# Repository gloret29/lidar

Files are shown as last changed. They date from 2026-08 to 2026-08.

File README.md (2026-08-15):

# Scanner 3D LiDAR DIY

Scanner d'intérieur sur trépied photo, à base d'un LiDAR 2D **STL-19P**
(FHL-LD19P, famille LD19) dont le plan de balayage vertical est mis en rotation
autour d'un axe vertical. L'ESP32-S3
acquiert les mesures et les diffuse en Wi-Fi ; la station hôte reconstruit le
nuage de points 3D.

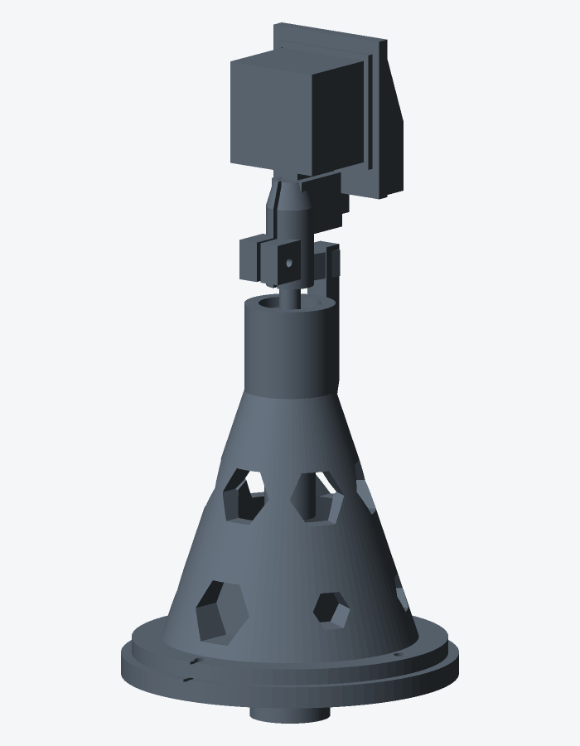
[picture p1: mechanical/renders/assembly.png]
Vue d'assemblage


**Environ 205 € de matériel**, pour un nuage de 225 000 à 900 000 points par
scan (selon durée), à ±5 cm, en 45 à 180 secondes.

## Documentation

### Comprendre

| Document | Contenu |
|---|---|
| [PROJECT.md](PROJECT.md) | Spécification et périmètre du projet |
| [docs/geometry.md](docs/geometry.md) | **Fondement mathématique** : pourquoi cette architecture, transformation exacte, budget d'erreur |
| [docs/architecture.md](docs/architecture.md) | Tâches du firmware, protocole UDP, pipeline hôte |

### Construire

| Document | Contenu |
|---|---|
| [docs/build.md](docs/build.md) | **Guide pas à pas** : de la commande au premier scan |
| [docs/bom.md](docs/bom.md) | Nomenclature complète, y compris les pièces manquantes |
| [docs/printing.md](docs/printing.md) | Réglages d'impression, calibration des ajustements |
| [docs/mechanical.md](docs/mechanical.md) | Conception cotée, justification des choix |
| [docs/assembly.md](docs/assembly.md) | Montage mécanique détaillé |
| [docs/wiring.md](docs/wiring.md) | Brochage, alimentation, plans SVG, réglage TMC2209 |
| [docs/wifi.md](docs/wifi.md) | Configuration réseau par portail captif |
| [docs/web.md](docs/web.md) | Panneau web : commande, matériel, diagnostics, réglages |
| [docs/ota.md](docs/ota.md) | Mise à jour du firmware par le réseau |

### Utiliser

| Document | Contenu |
|---|---|
| [docs/calibration.md](docs/calibration.md) | Les cinq mesures à effectuer une fois |
| [docs/operation.md](docs/operation.md) | Préparation des lieux, conduite d'un scan, dépannage |
| [docs/open3d.md](docs/open3d.md) | Visualisation, `.pcd`, recalage et maillage avec Open3D |

## Principe

Le STL-19P est un LiDAR **2D** (protocole LD19) : il balaie 360° dans un plan,
à **5 000 mesures/s**, avec détection du verre. Monté **sur la tranche**, ce
plan devient vertical ; en le faisant pivoter de 180° autour de l'axe vertical,
on couvre la sphère complète exactement une fois.

Conséquence contre-intuitive mais essentielle : **l'angle interne du LiDAR est
l'élévation, et l'angle moteur est l'azimut**.

$$
X = \rho \cos\psi \cos\theta, \quad
Y = \rho \sin\psi \cos\theta, \quad
Z = \rho \sin\theta
$$

Le détail, et le contre-exemple qui disqualifie la formulation inverse, sont
dans [docs/geometry.md](docs/geometry.md).

## Structure du dépôt

```
lidar/
├── firmware/            ESP32-S3 (PlatformIO / Arduino / FreeRTOS)
│   ├── boards/          DevKitC-1 N16R8 (16 Mo + PSRAM)
│   ├── data/            image LittleFS
│   ├── include/         config, protocole, pilotes
│   └── src/             amorce OTA, tâches, parseur LD19, axe de lacet
├── host/                Station hôte Python
│   ├── src/lidar_host/  protocole, transformation, visualisation, simulateur
│   ├── tests/           tests protocole / géométrie / simulateur (sans matériel)
│   └── calibration.json paramètres de calibration
├── mechanical/
│   ├── openscad/        sources paramétriques
│   ├── stl/             pièces prêtes à imprimer
│   ├── renders/         aperçus
│   └── tools/           génération et rendu
└── docs/                documentation détaillée
```

## Démarrage rapide

Le parcours complet (commande → impression → montage → firmware → premier
scan) est dans **[docs/build.md](docs/build.md)**.

### 1. Pièces mécaniques

```bash
cd mechanical/openscad
make                       # STL dans ../stl/
```

Imprimer **`test_fits` en premier** pour calibrer les ajustements, reporter les
valeurs dans `params.scad`, puis relancer `make`. Détails dans
[docs/printing.md](docs/printing.md).

### 2. Firmware

```bash
cd firmware
pio run -e seed -t upload     # amorce OTA, une fois en USB
pio device monitor
```

Au premier démarrage, se connecter au point d'accès `LiDAR-Scanner-Setup` pour
configurer le Wi-Fi, l'adresse de la station hôte et le mot de passe OTA.
Puis téléverser le firmware scanner : `pio run -e ota -t upload` (voir
[docs/build.md](docs/build.md) § 6.2).

Le scanner **reste au repos** après connexion. Ouvrir
`http://lidar-scanner.local/` pour lancer un balayage, vérifier l'état du
**matériel** connecté (LiDAR, entraînement, IMU), ajuster les réglages et
redémarrer si besoin. Voir [docs/web.md](docs/web.md).

Les mises à jour passent par le réseau, sans rebrancher l'USB — soit depuis
PlatformIO, soit en déposant le `.bin` sur la même page :

```bash
pio run -e ota -t upload      # firmware scanner
pio run -e ota -t uploadfs    # filesystem LittleFS
# si lidar-scanner.local ne résout pas :
pio run -e ota -t upload --upload-port 192.168.x.x
```

Voir [docs/ota.md](docs/ota.md).

### 3. Station hôte

```bash
cd host
python -m venv .venv && source .venv/bin/activate
pip install -e .
```

Sans matériel, valider la chaîne avec le simulateur UDP (deux terminaux) :

```bash
# A — sous WSL : export DISPLAY=:0 si la fenêtre Open3D échoue
lidar-visualize --port 9000

# B
lidar-simulate --host 127.0.0.1 --port 9000 --fast
```

Sans fenêtre graphique : `lidar-receive --port 9000 --output scans/sim.pcd --auto-stop`.

Avec le scanner : lancer d'abord `lidar-visualize` / `lidar-receive`, puis le
balayage depuis `http://lidar-scanner.local/`.

Guide Open3D : [docs/open3d.md](docs/open3d.md).

### 4. Post-traitement

```bash
lidar-receive --port 9000 --output scans/salon_pos1.pcd --auto-stop
lidar-register scans/salon_*.pcd --output salon.pcd
lidar-mesh salon.pcd --output salon.ply
```

## Ce que fait — et ne fait pas — ce scanner

| Usage | Adapté |
|---|---|
| Plan d'étage, surfaces, volumes | Oui |
| Modèle d'ambiance pour de la 3D | Oui |
| Vérifier l'encombrement d'un meuble | Oui |
| BIM de détail, détection de collisions | Non |
| Relevé patrimonial, contrôle au millimètre | Non |

Précision réaliste : **±5 cm**, espacement des points de 3 à 7 cm à 5 m. Un
scanner terrestre professionnel atteint ±2 mm et des dizaines de millions de
points, pour 15 000 à 50 000 €.

## Matériel

ESP32-S3 DevKitC-1 (N16R8) · LiDAR STL-19P (FHL-LD19P) · NEMA 17 pas à pas
(17HS4401 ou équivalent 4 fils) · TMC2209 · MPU6050 · 2 × roulements 608ZZ ·
power bank USB-C PD + trigger 12 V + buck 5 V · châssis imprimé en 3D avec
insert laiton 1/4"-20 × 10 × 8 mm.

Nomenclature détaillée, y compris les compléments à acquérir, dans
[docs/bom.md](docs/bom.md).

## Licence

MIT

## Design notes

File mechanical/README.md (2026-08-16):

# Mécanique

Pièces du châssis, entièrement paramétriques (OpenSCAD).

Assemblage

## Contenu

```
mechanical/
├── openscad/     sources paramétriques
│   ├── params.scad       TOUTES les cotes, point d'entrée unique
│   ├── lib.scad          primitives réutilisables
│   ├── test_fits.scad    coupon de calibration
│   ├── test_lidar_fit.scad  coupon empreinte STL-19P
│   ├── base_plate.scad   01 — plateau de base
│   ├── bearing_tower.scad 02 — colonne à roulements
│   ├── lidar_cradle.scad 03 — berceau LiDAR
│   ├── electronics_box.scad / _lid.scad  04/05 — boîtier
│   ├── assembly.scad     vue d'ensemble
│   └── Makefile
├── stl/          pièces prêtes à imprimer
├── renders/      aperçus
└── tools/
    ├── render_all.sh     génération STL + PNG
    └── stl_preview.py    rasteriseur STL en Python pur
```

## Génération

```bash
cd openscad
make                # STL dans ../stl/
make renders        # PNG (nécessite un contexte OpenGL)
```

Sans serveur graphique — machine distante, conteneur, CI — utiliser le
rasteriseur en Python pur, qui n'a aucune dépendance :

```bash
OPENSCAD=/chemin/vers/openscad ./tools/render_all.sh
```

```bash
# Aperçu d'une pièce isolée, sous l'angle de son choix
python3 tools/stl_preview.py stl/bearing_tower.stl /tmp/apercu.png \
    --azim 40 --elev 20 --color 5aa469
```

## Paramétrage

Toutes les cotes sont dans
[`openscad/params.scad`](openscad/params.scad). Modifier une valeur et relancer
`make` la propage à l'ensemble des pièces.

Les deux paramètres à ajuster impérativement avant d'imprimer :

| Paramètre | Comment l'obtenir |
|---|---|
| `fit_press`, `fit_slide` | Imprimer `test_fits`, voir [docs/printing.md](../docs/printing.md) |
| `lidar_optical_offset` | Mesurer au pied à coulisse, voir [docs/calibration.md](../docs/calibration.md) § 1 |

## Pièces

| Pièce | Rôle | Impression |
|---|---|---|
| `test_fits` | **À imprimer en premier** : calibration des ajustements | 15 min |
| `test_lidar_fit` | Empreinte STL-19P (trous + nappe) sans le berceau | ~20 min, à plat |
| `base_plate` | Interface trépied, support moteur, embase colonne | Retournée |
| `bearing_tower` | Porte les deux 608ZZ, **définit l'axe** | 5 périmètres, 40 % |
| `lidar_cradle` | Présente le STL-19P (3 oreilles M2,5) sur la tranche | Couchée |
| `electronics_box` + `_lid` | Boîtier sanglé sur le trépied | Standard |

Voir [docs/mechanical.md](../docs/mechanical.md) pour les cotes et la
justification des choix, [docs/printing.md](../docs/printing.md) pour les
réglages, [docs/assembly.md](../docs/assembly.md) pour le montage.

## Vérification

Les six pièces sont rendues sans erreur par OpenSCAD et produisent des solides
manifold. Les contraintes de non-collision (tige contre corps du STL-19P, voile
contre LiDAR, cavité contre moteur, têtes de vis contre cône) sont listées avec
leurs marges dans [docs/mechanical.md](../docs/mechanical.md) § 5.

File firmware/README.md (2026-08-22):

# Firmware ESP32-S3

Firmware PlatformIO du scanner 3D LiDAR.

## Prérequis

- [PlatformIO](https://platformio.org/) (CLI ou extension VS Code / Cursor).
  Sans `pio` dans le PATH : `firmware/.pio-venv/bin/pio`.
- ESP32-S3 DevKitC-1 **N16R8** (16 Mo Flash / 8 Mo PSRAM octale)

## Compilation

Premier flash, **obligatoirement en USB** : l'amorce OTA. Elle ne pilote
ni le LiDAR ni le moteur. Elle ouvre le portail Wi-Fi, puis accepte les
mises à jour du firmware **et** du filesystem LittleFS. Ensuite, plus
besoin de câble.

```bash
pio run -e seed -t upload
pio device monitor
```

Au premier démarrage, se connecter à `LiDAR-Scanner-Setup` pour le Wi-Fi
et le mot de passe OTA. Puis ouvrir `http://lidar-scanner.local/`.

Les mises à jour suivantes, sans USB :

```bash
pio run -e ota -t upload      # firmware scanner
pio run -e ota -t uploadfs    # image LittleFS (data/)
# si mDNS échoue :
pio run -e ota -t upload --upload-port 192.168.x.x
```

Pour itérer sur l'amorce elle-même : `pio run -e seed-ota -t upload`.
Le firmware scanner se compile encore avec `-e usb` si un câble est
branché.

Les dépendances (`WiFiManager`, `TMCStepper`) sont téléchargées automatiquement.
Web + OTA n'en ajoutent aucune : `ArduinoOTA`, `WebServer`, `Update`,
`LittleFS` et `Preferences` font partie du core ESP32.

## Configuration

### Wi-Fi et panneau web — aucun identifiant en dur

Au premier démarrage, l'ESP32 ouvre le point d'accès `LiDAR-Scanner-Setup`. On
y renseigne le réseau local, l'adresse de la station hôte et le mot de passe
du panneau (OTA inclus). Ces valeurs sont persistées en NVS.

Après connexion, ouvrir `http://lidar-scanner.local/` : commande de balayage,
section **Matériel** (Wi‑Fi, LiDAR, entraînement, IMU), diagnostics,
réglages StallGuard / courants / vitesse, redémarrage et OTA.

Voir [docs/wifi.md](../docs/wifi.md), [docs/web.md](../docs/web.md) et
[docs/ota.md](../docs/ota.md).

### Paramètres

- Défauts et brochage : [`include/config.h`](include/config.h)
- Valeurs runtime (persistées) : panneau web → NVS namespace `scanset`

> **Attention** : sur la variante N16R8, les GPIO 33 à 37 sont occupés par la
> PSRAM octale. Les utiliser fait planter la carte au démarrage.

## Organisation

```
firmware/
├── platformio.ini
├── boards/              ESP32-S3 DevKitC-1 N16R8 (16 Mo + PSRAM)
├── data/                image LittleFS (`pio run -t uploadfs`)
├── include/
│   ├── config.h        brochage et défauts
│   ├── protocol.h      datagrammes UDP (v2)
│   ├── ld19.h          analyseur de trames LiDAR
│   ├── mpu6050.h       nivellement IMU, détection de choc
│   ├── scanner.h       axe de lacet
│   ├── settings.h      réglages NVS
│   ├── control.h       file de commandes
│   ├── status.h        télémétrie
│   ├── ota.h           panneau web + OTA
│   └── wifi_setup.h
└── src/
    ├── seed/main.cpp   amorce OTA (premier flash USB)
    ├── main.cpp
    ├── ld19.cpp
    ├── mpu6050.cpp
    ├── scanner.cpp
    ├── settings.cpp
    ├── control.cpp
    ├── status.cpp
    ├── ota.cpp         page unique + ArduinoOTA (firmware + LittleFS)
    └── wifi_setup.cpp
```

## Séquence d'exécution

```
setup()
  ├── réglages NVS
  ├── UART LiDAR + PWM
  ├── TMC2209
  ├── MPU6050 (I2C)
  ├── WiFiManager
  ├── panneau web + ArduinoOTA
  └── tâches

motion_task    attend start/stop/rehome/estop (file FreeRTOS)
lidar_task     UART -> décodage -> file
network_task   file -> datagrammes UDP
web_task       HTTP + ArduinoOTA.handle()
```

Le scanner **ne lance plus de balayage tout seul** au démarrage.

## Points d'implémentation notables

**Les points partent en polaire brut.** La conversion cartésienne est faite
côté hôte. Voir [docs/architecture.md](../docs/architecture.md).

**Débordement de file : on abandonne le point.** Perdre un point est sans
conséquence ; bloquer l'UART corromprait toute une salve.

**StealthChop2 n'est pas un confort.** Les vibrations SpreadCycle se
transmettent au capteur optique.

**L'OTA coupe le moteur avant d'écrire**, et est refusé pendant un balayage.
Comme le scanner démarre au repos, un firmware défectueux reste rattrapable
sans fenêtre artificielle de 10 s. Détails dans [docs/ota.md](../docs/ota.md).

**Les réglages exposés sont bornés dans le firmware** (courants, StallGuard,
vitesse). La calibration géométrique reste sur l'hôte.

## État

Firmware **0.4.5** — homing StallGuard par UART (`SG_RESULT`), sans broche DIAG.

| Fonction | Code | Validation matérielle |
|---|---|---|
| Amorce OTA (`seed`) | OK | OTA firmware + LittleFS |
| Scanner + panneau web | OK | Wi‑Fi, reboot, section Matériel |
| Parseur STL-19P / LD19 | OK | CRC % sur panneau |
| MPU6050 nivellement + choc | OK | `imu_ok` sur panneau |
| TMC2209 + homing StallGuard | OK | Ligne Entraînement → OK après rehome |
| Balayage complet | OK | Premier `.pcd` réel |

À vérifier au montage final :

- [ ] LiDAR : CRC ≥ 95 %, Hz mesuré ≈ consigne (5 Hz)
- [ ] Entraînement : pastille **OK** après **Rehomer** réussi
- [ ] MPU6050 : pastille **OK**, vecteur **g** affiché
- [ ] Scan 180° → `.pcd` cohérent dans Open3D

Le premier téléversement se fait obligatoirement **par USB**, avec
l'environnement `seed`. Les suivants passent par le réseau
(`-e ota -t upload` / `uploadfs`) ou la page web.

La géométrie et le protocole sont couverts par les tests de `host/tests/`.

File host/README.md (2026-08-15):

# Station hôte

Réception UDP, conversion cartésienne, visualisation temps réel et
post-traitement du nuage de points.

## Installation

```bash
python -m venv .venv
source .venv/bin/activate
pip install -e .
# sous WSL2 + WSLg, si lidar-visualize échoue :
export DISPLAY=:0
```

Python ≥ 3.10. Dépendances : NumPy et Open3D. Les commandes `lidar-*` sont
installées par `pip install -e .` (pas besoin de `PYTHONPATH`).

## Utilisation

### Visualisation pendant le scan

```bash
lidar-visualize --port 9000
```

Sous WSL sans affichage : `--headless --output scans/out.pcd`, ou
`lidar-receive` (voir [docs/open3d.md](../docs/open3d.md)).

### Flux de test sans matériel

Dans un terminal :

```bash
lidar-visualize --port 9000
```

Dans un autre :

```bash
lidar-simulate --host 127.0.0.1 --port 9000 --fast
```

Le simulateur envoie une scène synthétique (protocole UDP v2) — par défaut
un **appartement en L avec mobilier** (`--scene apartment`) — **et enregistre**
le nuage dans `scans/simulate.pcd`. Un exemplaire est versionné dans le dépôt,
ainsi que le maillage `scans/simulate.ply`.

```bash
python -c "import open3d as o3d; o3d.visualization.draw_geometries([o3d.io.read_point_cloud('scans/simulate.pcd')])"
python -c "import open3d as o3d; m=o3d.io.read_triangle_mesh('scans/simulate.ply'); m.compute_vertex_normals(); o3d.visualization.draw_geometries([m])"
```

```bash
# Fichier seul, sans UDP
lidar-simulate --fast --no-udp --output scans/sim.pcd

# Pavé vide (ancien comportement)
lidar-simulate --fast --scene box --no-udp

# UDP sans fichier
lidar-simulate --fast --no-save
```

Options : `--scene`, `--width`, `--depth`, `--height`, `--speed`, `--psi-end`,
`--loops 0`, `--calibration`. Détails dans
[docs/open3d.md](../docs/open3d.md#flux-de-test-sans-matériel).

### Enregistrement

```bash
lidar-receive --port 9000 --output scans/salon_pos1.pcd --auto-stop
```

`--auto-stop` arrête la capture à réception du drapeau de fin de balayage.

### Recalage et maillage

```bash
lidar-register scans/salon_*.pcd --output salon.pcd
lidar-mesh salon.pcd --output salon.ply --depth 8 --smooth taubin
# ou relisser un .ply existant :
lidar-mesh scans/simulate.ply --output scans/simulate_smooth.ply --smooth-iter 20
```

## Calibration

[`calibration.json`](calibration.json) regroupe le bras de levier, les
décalages angulaires et le vecteur gravité de référence (`g_zero`, relevable
depuis la section **Matériel** du panneau web). Ces valeurs sont appliquées
**au post-traitement** : les corriger et rejouer un scan ne demande ni
reflashage ni nouvelle acquisition.

Procédures détaillées dans [docs/calibration.md](../docs/calibration.md).

Guide Open3D (fenêtre live, fichiers, ICP, Poisson, dépannage) :
[docs/open3d.md](../docs/open3d.md).

## Tests

```bash
pytest -q
```

38 tests, sans matériel. Ils couvrent le décodage du protocole, la
transformation géométrique (garde-fou contre la formule sphérique naïve) et
le simulateur UDP (dont l'enregistrement du nuage).

## Organisation

```
host/
├── src/lidar_host/
│   ├── protocol.py     décodage UDP v2, vectorisé NumPy
│   ├── transform.py    polaire -> cartésien, calibration, nivellement
│   ├── receiver.py     socket, accumulation, export
│   ├── visualize.py    affichage temps réel Open3D
│   ├── simulate.py     flux UDP de test (pièce synthétique)
│   └── postprocess.py  filtrage, ICP, Poisson
├── tests/
└── calibration.json
```

## Protocole

Spécifié dans
[docs/architecture.md](../docs/architecture.md#protocole-udp-version-2). Les
points arrivent en **polaire brut** : distance et angle d'élévation par point,
azimut en en-tête de datagramme.

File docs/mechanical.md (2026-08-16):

# Conception mécanique

Toutes les cotes sont en millimètres. Le repère d'assemblage a son origine
$z = 0$ sur la **face supérieure du plateau de base**, l'axe $Z$ confondu avec
l'axe de rotation (lacet).

Vue d'assemblage

## 1. Chaîne cinématique

```
                    STL-19P (couché, plan de balayage vertical)
                       │  centre optique : z = 205, sur l'axe
                  ┌────┴────┐
                  │ berceau │  C3 — serre sur la tige
                  └────┬────┘
                       │  tige acier Ø8, z 65 → 180
                  ┌────┴────┐
                  │ 608ZZ   │  z 122 (palier de butée : reprend le poids)
                  │ colonne │  C2
                  │ 608ZZ   │  z 82  (palier de guidage)
                  └────┬────┘
                       │  accouplement flexible 5→8, z 52 → 77
                  ┌────┴────┐
                  │ NEMA 17 │  z 0 → 40
                  └────┬────┘
                  ┌────┴────┐
                  │ plateau │  C1
                  └────┬────┘
                       │  insert 1/4"-20
                    trépied
```

Hauteur totale au-dessus de la semelle du trépied : **229 mm**.
Masse de la tête tournante : environ 110 g (STL-19P ~47 g + berceau 45 g + tige).

## 2. Décisions de conception

### Entraînement direct plutôt que courroie

Le TMC2209 en 1/16 de pas donne $360 / (200 \times 16) = 0{,}1125°$ par
micro-pas, soit 3,5 fois plus fin que le pas de balayage visé (0,4°). Une
réduction par courroie n'apporterait donc aucune résolution utile, tout en
introduisant du jeu et une pièce d'usure supplémentaire. L'entraînement direct
supprime totalement le jeu de renversement.

### Moteur au-dessus du plateau, coaxial

L'axe de rotation et la vis de trépied doivent tous deux passer par le centre.
Le conflit se résout en plaçant le moteur **sur** le plateau (arbre vers le
haut) et l'insert 1/4"-20 **sous** le plateau, dans un bossage. La colonne
coiffe alors le moteur.

### Accouplement flexible, pas rigide

Deux roulements sur une tige rigide plus un accouplement rigide vers le moteur
forment un système hyperstatique : le moindre défaut d'alignement précontraint
les roulements et crée un point dur. Un accouplement à mâchoires absorbe ce
défaut.

### Palier de butée en haut

Le roulement supérieur (z 122) reprend la charge axiale : le moyeu du berceau
prend appui sur sa bague intérieure. Le chemin d'effort est donc
LiDAR → berceau → bague intérieure → billes → bague extérieure → épaulement de
la colonne → plateau → trépied. Le roulement inférieur (z 82) ne travaille
qu'en radial.

## 3. Occultation au nadir

Tout ce qui se trouve sous le LiDAR et sur l'axe se trouve **dans** le plan de
balayage et masque une portion de la sphère autour du nadir.

| Élément | Ø | Distance sous le centre optique | Demi-angle masqué |
|---|---|---|---|
| Sommet du moyeu | 12 | 25 | 13,5° |
| Voile du berceau | 14 (en Y) | 25 | 15,6° |
| Sommet de la colonne | 34 | 72 | 13,3° |
| Contrefort de butée | 48 (local) | 53 | 24° sur un seul azimut |

Le cône aveugle fait donc environ **20° de demi-angle**, plus un secteur
étroit à l'azimut du contrefort. Sur un trépied à 1,50 m, cela correspond à un
disque de sol d'environ 0,55 m de rayon autour des pieds — que l'on comble
depuis une seconde position de scan. Un scanner terrestre professionnel perd
exactement la même zone.

La platine du berceau, elle, est parallèle au plan de balayage et décalée de
22 mm : deux plans parallèles ne se coupent jamais, elle n'occulte donc rien.

## 4. Cotes principales

### C1 — Plateau de base

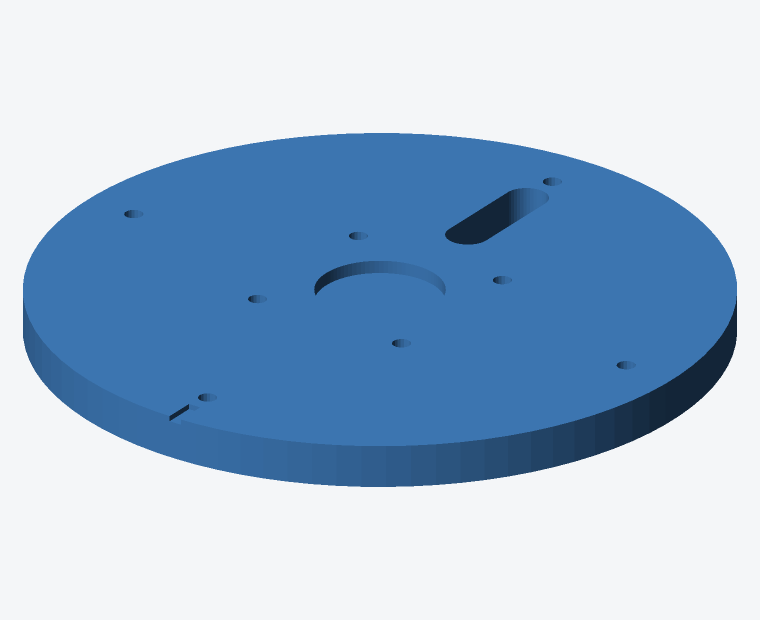
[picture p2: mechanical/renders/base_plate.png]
Plateau de base


| Cote | Valeur |
|---|---|
| Diamètre | 126 |
| Épaisseur | 8 |
| Bossage trépied | Ø30 × 16 vers le bas |
| Logement d'insert | Ø8,4 × 13, par le dessous — insert **1/4"-20 × 10 × 8 mm** |
| Fixation moteur | 4 × M3 traversants, carré 31 — **écrou M3** côté bride NEMA |
| Fixation colonne | 4 × M3 sur Ø106, écrous noyés par le dessous |
| Passage de câbles | Lumière 18 × 8 à 180° |

Les vis du moteur passent par le plateau ; l'**écrou M3** se pose côté bride
NEMA (trous traversants sur les 17HS4401 courants).

### C2 — Colonne à roulements

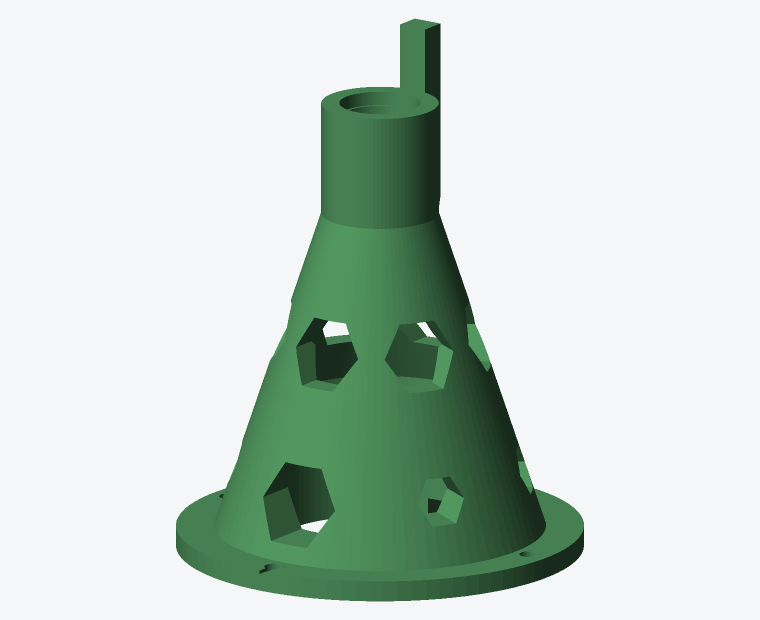
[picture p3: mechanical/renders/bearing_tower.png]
Colonne


| Cote | Valeur |
|---|---|
| Bride | Ø118 × 6 |
| Base du cône | Ø96 |
| Col | Ø34 |
| Hauteur totale | 133 |
| Cavité moteur | Ø62 jusqu'à z 42 |
| Gorge d'accouplement | Ø26 |
| Logement roulement bas | Ø22,15 × 7 à z 82 |
| Dégagement intermédiaire | Ø23,5 |
| Logement roulement haut | Ø22,15 × 7 à z 122 |

Les trois fenêtres hexagonales à z 64 donnent accès **aux vis de
l'accouplement**, inaccessibles une fois la colonne posée. Elles ne sont pas
décoratives.

Le contrefort dorsal sert de **butée mécanique** pour la prise de référence
d'azimut par StallGuard, sans capteur.

### C3 — Berceau LiDAR

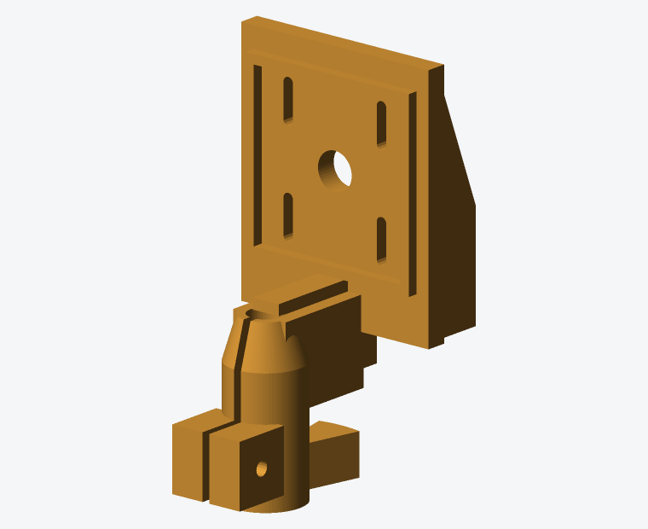
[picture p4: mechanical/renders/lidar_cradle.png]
Berceau


| Cote | Valeur |
|---|---|
| Moyeu | Ø18, serrage sur 40 mm de tige, alésage Ø8,45, rétreint à Ø12 en tête |
| Fente de serrage | 1,8 mm + vis M3×25 |
| Platine | 5 mm d'épaisseur, à x = −22 (= décalage optique) |
| Fixation STL-19P | 3 × M2,5 — 2 oreilles à **10,77 mm** du bord câble, 1 à **42,69 mm** (entraxe 31,92) |
| Passage câble | Fente **16 mm** ouverte en bas, **traversante** platine + rebord |
| Rebord de centrage | **54 × 46,3**, hauteur 2,5 |
| Secteur de butée | 26° sur Ø48 |

Les trous M2,5 suivent le **datasheet STL-19P § 5.1** (face de fixation) :
corps 38,59 × 38,59, entraxe latéral 46,8 mm, entraxe vertical **31,92 mm**.
Le connecteur et les **2 oreilles** sont du même côté (bas du berceau) ;
l'oreille simple est à l'opposé.
Mesurer quand même le décalage optique sur l'exemplaire réel.

### C4/C5 — Boîtier électronique

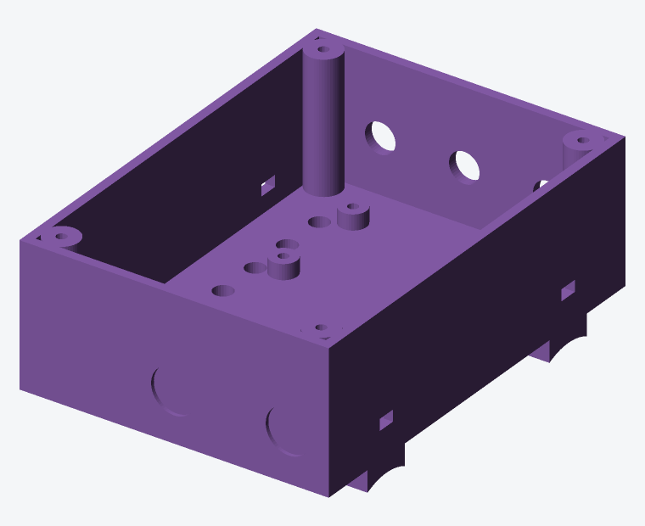
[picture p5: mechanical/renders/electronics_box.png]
Boîtier


Volume intérieur 106 × 76 × 34. Il se **sangle sur la colonne centrale du
trépied** par deux berceaux en Ø32 sous le fond. L'électronique reste ainsi au
sol : la tête tournante ne porte que le LiDAR et son câble, et le trépied
n'est pas déséquilibré par une masse en porte-à-faux.

## 5. Contraintes de non-collision vérifiées

Ces contraintes sont vérifiées géométriquement dans les sources OpenSCAD et
ont été validées par rendu.

| Contrainte | Marge |
|---|---|
| Sommet de la tige (z 180) sous le corps du STL-19P (z 181,9) | **1,9 mm** |
| Voile du berceau (z ≤ 179) sous le corps (z ≥ 182) | **~3 mm** |
| Cavité de la colonne Ø62 / diagonale NEMA 17 Ø59,8 | 1,1 mm au rayon |
| Paroi de la colonne au droit de la cavité | 4,2 mm mini |
| Vis de colonne (R 53) hors du cône (R 48) | 5 mm, têtes accessibles |
| Nervures dorsales du berceau côté −X | hors volume LiDAR |

**La tige ne doit pas dépasser 115 mm** : au-delà elle pénètre dans le corps
du STL-19P (encombrement plus haut que l'ancien LD19 plat 38,6 mm).

## 6. Impression 3D

Guide détaillé (coupon, insert trépied, contrôles) :
[printing.md](printing.md).

### Réglages généraux

| Paramètre | Valeur | Remarque |
|---|---|---|
| Matériau | **PETG** | Recommandé — stable en chaleur, rigide |
| Buse | 0,4 mm | |
| Hauteur de couche | **0,2 mm** | Sauf `test_fits` : 0,28 mm |
| Températures | 240 °C / 80 °C | Ajuster au filament |
| Refroidissement | ~40 % | Trop froid fragilise le PETG |
| Rétraction | Profil PETG du slicer | Le PETG file facilement |
| Adhérence plateau | PEI + colle barbie / laque | Bride de colonne : surface plane critique |

Le PLA convient pour un essai, mais se déforme dès 50 °C — à éviter en
extérieur ou en voiture.

### Réglages par pièce

| Pièce | Périmètres | Remplissage | Orientation | Supports | Durée indic. |
|---|---|---|---|---|---|
| `test_fits` | 2 | 10 % | Telle quelle | Non | 20–30 min |
| `base_plate` | 4 | 30 % | **Retournée**, bossage trépied vers le haut | Non | ~1 h 30 |
| `bearing_tower` | **5** | **40 %** | Bride sur le plateau | Non | ~4 h |
| `lidar_cradle` | 4 | 35 % | **Couchée**, platine à plat (`rotate -90° Y`) | Sous le moyeu | ~1 h |
| `electronics_box` | 3 | 20 % | Ouverture vers le haut | Non | ~1 h |
| `electronics_lid` | 3 | 20 % | À plat | Non | ~15 min |

**Total** : environ 9 h et 220 g de filament.

Points d'attention :

- **`bearing_tower`** — pièce la plus critique : ne pas réduire les 5
  périmètres ni les 40 % de remplissage. Toute souplesse ici se traduit en
  erreur angulaire dans le nuage.
- **`base_plate` retournée** — face supérieure sur le plateau : pas de
  surplomb, face moteur plane.
- **`lidar_cradle` couchée** — couches perpendiculaires au porte-à-faux du
  LiDAR ; imprimée debout, la pièce casse au voile.

### Ajustements dimensionnels (calibrés)

Imprimer le coupon **`test_fits` en premier**. Reporter les valeurs retenues
dans [`params.scad`](../mechanical/openscad/params.scad) :

| Paramètre | Valeur calibrée | Effet |
|---|---|---|
| `fit_press` | **0,15** | Logement 608ZZ → **Ø22,15** (encoche 5) |
| `fit_slide` | **0,45** | Alésage tige → **Ø8,45** (encoche 4) |

Puis regénérer les STL : `cd mechanical/openscad && make`.

## 7. Matériau et rigidité

Le **PETG** est recommandé : il est plus rigide et bien plus stable
dimensionnellement que le PLA dans une voiture ou un local chaud, et moins
capricieux que l'ABS.

Points de rigidité structurants :

- La **colonne** détermine la précision angulaire : respecter **5 périmètres**
  et **40 %** de remplissage (voir § 6).
- L'entraxe des deux roulements (40 mm) fixe la rigidité en basculement. Le
  réduire dégraderait directement la précision.
- Le **moyeu du berceau** serre sur 40 mm de tige, ce qui suffit largement pour
  110 g en porte-à-faux de 40 mm.

## 8. Génération des pièces

```bash
cd mechanical/openscad
make                # STL dans ../stl/
make renders        # aperçus PNG (nécessite un contexte OpenGL)
```

Sans serveur graphique, utiliser le rasteriseur en Python pur du dépôt :

```bash
cd mechanical
OPENSCAD=/chemin/vers/openscad ./tools/render_all.sh
```

Tous les paramètres sont centralisés dans
[`params.scad`](../mechanical/openscad/params.scad). Modifier une cote et
relancer `make` propage le changement à toutes les pièces.

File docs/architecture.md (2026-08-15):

# Architecture logicielle

## Vue d'ensemble

```
   ┌──────────────────── Tête tournante ────────────────────┐
   │   STL-19P  (plan vertical, 5 Hz, 5000 pts/s)   │
   └────────────────────────┬───────────────────────────────┘
                            │ UART 230400
   ┌────────────────────────┴───────────────────────────────┐
   │                      ESP32-S3                          │
   │                                                        │
   │   lidar_task  ──►  file  ──►  network_task             │
   │   (coeur 1)                   (coeur 0)                │
   │        ▲                                               │
   │   motion_task ──► TMC2209 ──► NEMA 17                  │
   │   (coeur 1)                                            │
   │                                                        │
   │   ota_task    ──► ArduinoOTA (3232) + web (80)         │
   │   (coeur 0)                                            │
   └────────────────────────┬───────────────────────────────┘
                            │ UDP, points POLAIRES BRUTS
   ┌────────────────────────┴───────────────────────────────┐
   │                   Station hôte                          │
   │   protocol ──► transform (calibration) ──► Open3D      │
   └────────────────────────────────────────────────────────┘
```

## Décision structurante : transmettre en polaire brut

La conversion cartésienne se fait **sur l'hôte**, pas sur l'ESP32.

L'argument n'est pas la bande passante — 36 ko/s en polaire contre 72 ko/s en
cartésien, les deux sont négligeables en Wi-Fi. L'argument est la
**reprocessabilité** : le bras de levier, le zéro d'azimut et le nivellement
sont des paramètres de calibration. Les garder côté hôte permet de corriger un
réglage et de rejouer un scan déjà enregistré, sans reflasher ni retourner sur
site.

C'est d'autant plus pertinent que la transformation est exactement l'endroit où
une erreur de conception s'était glissée initialement (voir
[geometry.md](geometry.md) § 3).

## Tâches du firmware

| Tâche | Cœur | Priorité | Rôle |
|---|---|---|---|
| `lidar_task` | 1 | 5 | Lecture UART, décodage des trames LD19, mise en file |
| `motion_task` | 1 | 4 | Nivellement IMU (10 s), homing StallGuard, profil de balayage |
| `network_task` | 0 | 3 | Agrégation en datagrammes, émission UDP |
| `ota_task` / `web_task` | 0 | 2 | Panneau web + OTA firmware **et** LittleFS ([web.md](web.md), [ota.md](ota.md)) |
| `loop()` | 0 | 1 | Télémétrie sur le port série |

La file entre `lidar_task` et `network_task` compte 2 048 entrées, soit environ
410 ms de marge à 5 000 pts/s. En cas de saturation, `lidar_task` **abandonne
le point** plutôt que de bloquer : perdre un point est sans conséquence, perdre
la synchronisation de l'UART corromprait toute une salve de trames.

### Synchronisation des angles

À 2 °/s, l'azimut ne varie que de **0,005°** pendant l'émission d'une trame de
12 points (2,7 ms). C'est trois ordres de grandeur sous la résolution visée
(0,4°). Relever $\psi$ une fois par trame suffit donc largement.

Les bornes `psi_start` et `psi_end` sont néanmoins transmises à chaque
datagramme, et l'hôte interpole selon l'horodatage : la chaîne reste correcte
si l'on décide un jour d'accélérer le balayage.

## Ports réseau

| Port | Protocole | Rôle |
|---|---|---|
| 9000 | UDP, sortant | Flux de points vers la station hôte |
| 3232 | TCP | Mise à jour ArduinoOTA / espota |
| 80 | TCP | Page de commande, `/info`, OTA web (`/update`, `/updatefs`) |

Le port 3232 n'est pas servi pendant un balayage, et le port 80 renvoie alors
503 sur `/update` et `/updatefs` : une mise à jour en pleine acquisition
perdrait le scan et laisserait la mécanique dans un état indéterminé.

Une mise à jour relâche `EN` du TMC2209 **avant** la première écriture en
flash, puis suspend `lidar_task` et `network_task`. Le scanner démarre au
repos (plus de balayage automatique) : l'OTA et le panneau de commande sont
joignables immédiatement. Détails dans [web.md](web.md) et [ota.md](ota.md).

## Protocole UDP, version 2

Port par défaut : **9000**. L'adresse de l'hôte se configure via le portail
WiFiManager ([wifi.md](wifi.md)). Tout est en little-endian.

### En-tête (32 octets)

| Offset | Type | Champ |
|---|---|---|
| 0 | `uint32` | Magic `0x4C444152` (« LDAR ») |
| 4 | `uint16` | Version du protocole (2) |
| 6 | `uint16` | Drapeaux |
| 8 | `uint32` | Numéro de séquence |
| 12 | `uint16` | Nombre de points |
| 14 | `uint16` | Vitesse du LD19, en 0,1 Hz |
| 16 | `uint64` | Horodatage du premier point (µs) |
| 24 | `int32` | Azimut au premier point (millidegrés) |
| 28 | `int32` | Azimut au dernier point (millidegrés) |

### Point (8 octets)

| Offset | Type | Champ |
|---|---|---|
| 0 | `uint16` | Distance $\rho$, millimètres |
| 2 | `uint16` | Angle LiDAR $\theta$ = **élévation**, centidegrés |
| 4 | `uint8` | Intensité |
| 5 | `uint8` | Réservé |
| 6 | `uint16` | Décalage depuis l'horodatage d'en-tête (µs) |

### Drapeaux

| Bit | Nom | Signification |
|---|---|---|
| 0 | `SCAN_START` | Premier datagramme d'un scan |
| 1 | `SCAN_END` | Balayage terminé |
| 2 | `LEVEL_VALID` | Nivellement IMU réussi |
| 3 | `SHOCK_DETECTED` | Le trépied a bougé : scan suspect |

120 points par datagramme, soit 992 octets — sous la MTU, donc jamais de
fragmentation IP.

Le numéro de séquence permet à l'hôte de chiffrer les pertes. UDP est retenu
sciemment : sur un nuage de plusieurs centaines de milliers de points, quelques
pertes sont sans importance, alors que la latence de retransmission de TCP
perturberait l'affichage temps réel.

## Station hôte

```
host/src/lidar_host/
├── protocol.py      décodage v2, vectorisé NumPy
├── transform.py     polaire -> cartésien, calibration, nivellement
├── receiver.py      socket UDP, accumulation, export
├── visualize.py     affichage temps réel Open3D
└── postprocess.py   filtrage, recalage ICP, maillage Poisson
```

Le décodage est vectorisé : `np.frombuffer` sur un dtype structuré, sans boucle
Python. Un datagramme de 120 points se décode en quelques microsecondes, très
loin des 37 datagrammes par seconde à absorber.

## Débit

| Étage | Débit |
|---|---|
| LD19 / STL-19P en sortie UART | 5 000 pts/s, soit ~19,6 ko/s de trames |
| Points valides après filtrage | ~5 000 pts/s (CRC + distance valide) |
| Charge utile UDP | ~32 ko/s |
| Avec en-têtes UDP/IP | ~34 ko/s |

Très largement dans les capacités d'un 802.11n, y compris en périphérie de
couverture.

## Amorce OTA

Le premier flash USB installe un firmware minimal (`src/seed/`) : Wi-Fi,
ArduinoOTA et page web, sans LiDAR ni moteur. Les mises à jour suivantes —
firmware scanner **et** image LittleFS — passent par le réseau. Voir
[ota.md](ota.md).

## Tests

```bash
cd host && PYTHONPATH=src .venv/bin/python -m pytest tests/ -q
```

38 tests couvrent le décodage du protocole et la transformation géométrique,
sans aucun matériel. Ils comprennent notamment un **garde-fou contre le retour
à la formule sphérique naïve** : c'est l'erreur la plus coûteuse possible sur
ce projet, car elle produit un nuage plausible mais faux.

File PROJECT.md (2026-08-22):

# Scanner 3D LiDAR DIY — spécification

> Document de référence, également utilisé comme contexte pour les assistants
> de développement.

## Objectif

Concevoir et fabriquer un scanner 3D d'intérieur autonome, à bas coût, montable
sur trépied photo standard, générant un nuage de points $(X, Y, Z)$
géoréférencé d'une pièce ou d'un bâtiment.

Budget matériel : environ **205 €**. Précision visée : **±5 cm**.

## Architecture retenue

Le STL-19P (FHL-LD19P, protocole LD19) est monté **couché sur la tranche** :
son plan de balayage est vertical
et contient l'axe de rotation. L'ensemble pivote de 180° autour de l'**axe
vertical**, entraîné en prise directe par un NEMA 17.

| Angle | Origine | Rôle |
|---|---|---|
| $\theta$ | Angle interne du LD19 | **Élévation** |
| $\psi$ | Angle moteur | **Azimut** |

$$
X = \rho \cos\psi \cos\theta, \quad
Y = \rho \sin\psi \cos\theta, \quad
Z = \rho \sin\theta
$$

Justification complète et budget d'erreur : [docs/geometry.md](docs/geometry.md).

### Pourquoi pas un basculement autour d'un axe horizontal

Tous les plans de balayage contiennent l'axe de rotation : ce sont donc des
grands cercles passant par deux pôles. Avec un axe vertical, ces pôles sont le
zénith et le nadir — le nadir étant de toute façon masqué par le trépied. Avec
un axe horizontal, ils tomberaient sur deux murs quelconques, produisant deux
taches hyper-denses entourées de zones clairsemées.

S'y ajoutent trois avantages : couple moteur constant (pas de gravité à
vaincre), absence de fléchissement variable, et axe de rotation naturellement
confondu avec la verticale.

## Matériel

### Mesure optique

LiDAR 2D DToF **LDRobot STL-19P** (FHL-LD19P) : portée 0,02 à 12 m,
**5 000 mesures/s**, 360°, **détection du verre**, UART 3,3 V à 230 400 bauds,
précision ±45 mm, tolérance 30 klux. Fixation mécanique : **3 oreilles M2,5**
(gauche, droite, haut — câble en bas), corps **54 × 46,29 × 35 mm**.

Vitesse de rotation pilotable par PWM de 5 à 13 Hz. Le firmware la règle à
**5 Hz**, ce qui double la résolution angulaire (0,4° au lieu de 0,8°) sans
contrepartie sur trépied.

### Entraînement

NEMA 17 **pas à pas 4 fils** (ex. **17HS4401**) piloté par **TMC2209** en
1/16 de pas, StealthChop2, en prise directe. Résolution : 0,1125° par
micro-pas, soit 3,5 fois plus fin que le pas de balayage. Guidage par deux
roulements **608ZZ** sur tige acier Ø8.

> **Incompatible** : moteur brushless BLDC type 42BL3802 (Amazon B097JKJ9VV) —
> pas de pilotage STEP/DIR, ne convient pas au TMC2209 ni au firmware.

Prise de référence d'azimut par **StallGuard4** contre une butée imprimée :
aucun capteur de fin de course.

### Calcul et télémétrie

**ESP32-S3 DevKitC-1 (N16R8)**, 16 Mo de Flash et 8 Mo de PSRAM. Configuration
réseau par portail captif WiFiManager.

**MPU6050** monté sur la **base fixe** — et non sur la tête tournante. Il ne
sert qu'au nivellement statique et à la détection de choc, jamais à la
correction angulaire point par point : son bruit de 0,5 à 1° dégraderait la
mesure d'un facteur 2 à 4 par rapport au moteur.

### Alimentation

Power bank USB-C PD → trigger 12 V (TMC2209) → buck 12 V/5 V 3 A (ESP32 et
LD19). Consommation d'environ 8 à 12 W en balayage.

### Châssis

Cinq pièces imprimées en PETG, paramétriques (OpenSCAD), avec insert laiton
1/4"-20 UNC pour trépied photo. Hauteur totale 229 mm, tête tournante de 110 g.

## Chaîne logicielle

### Firmware (C++ / FreeRTOS)

| Tâche | Rôle |
|---|---|
| `lidar_task` | Décodage des trames LD19 (47 octets, CRC8 polynôme 0x4D) |
| `motion_task` | Nivellement IMU (10 s), homing StallGuard, profil de balayage |
| `network_task` | Agrégation et émission UDP |
| `ota_task` / panneau web | Commande, matériel, diagnostics, réglages NVS, reboot, OTA |

Les points sont transmis en **polaire brut** $(\rho, \theta)$, avec l'azimut en
en-tête de datagramme. La conversion cartésienne est faite côté hôte, ce qui
permet de corriger la calibration et de rejouer un scan **sans reflasher ni
rescanner**.

Le scanner démarre au repos. Les balayages se lancent depuis
`http://lidar-scanner.local/` (ou l'API). Le premier flash USB installe une
**amorce OTA** (Wi-Fi + mises à jour firmware/filesystem) ; le firmware
scanner arrive ensuite par le réseau. Le moteur est coupé avant toute
écriture en flash.

### Station hôte (Python)

Décodage vectorisé NumPy, transformation avec calibration (bras de levier,
décalages angulaires, redressement sur la gravité), visualisation temps réel
Open3D, recalage ICP multi-positions, maillage Poisson, export `.pcd` / `.ply`.
Un simulateur UDP (`lidar-simulate`) permet de valider toute la chaîne sans
scanner.

## Contraintes de conception

1. Le centre optique du STL-19P doit être aussi proche que possible de l'axe de
   rotation. Le résidu se compense en post-traitement : ignoré, il courbe les
   murs de façon **systématique**, donc non filtrable.
2. Le moteur est la référence angulaire. L'IMU ne sert qu'au nivellement.
3. Un cône d'environ 20° de demi-angle est perdu au nadir, masqué par la
   colonne. On le comble depuis une seconde position de scan.
4. Repère : origine au centre optique, $Z$ aligné sur la gravité après
   redressement IMU.

## État d'avancement

| Volet | Statut |
|---|---|
| Géométrie et mathématiques | Validées, 38 tests automatisés |
| Pièces 3D | 6 pièces paramétriques, rendues et vérifiées |
| Documentation de construction | Complète |
| Firmware | **0.4.5** — homing StallGuard par UART (sans DIAG) ; LiDAR / moteur en attente de câblage UART |
| Station hôte | Protocole, transform, Open3D, simulateur UDP, tests |
| Calibration | Procédures écrites ; `g_zero` relevable depuis le panneau web |

## Limites connues

- **Miroirs** : produisent une pièce virtuelle complète et géométriquement
  cohérente. Aucun filtrage ne les élimine ; il faut les couvrir.
- **Vitres** : la variante **STL-19P** détecte le verre (surface mesurée sur
  la vitre). Fermer les volets reste utile pour une surface opaque derrière et
  pour limiter l'éblouissement solaire.
- **Densité** : environ 450 000 points par scan standard (90 s à 5 000 pts/s),
  contre des dizaines de millions pour un scanner professionnel.
- **Nadir** : cône aveugle d'environ 20°, comblé par une seconde station.

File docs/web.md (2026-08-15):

# Panneau web embarqué

Le scanner expose une page unique sur le port 80, protégée par le même mot de
passe que l'OTA (`admin` / valeur du portail WiFiManager).

```
http://lidar-scanner.local/
```

Ou l'adresse IP affichée au démarrage série.

## Ce que fait la page

Six sections, un seul écran :

| Section | Rôle |
|---|---|
| **Commande** | Lancer, arrêter, rehomer, arrêt d'urgence, **redémarrer** |
| **Matériel** | État opérationnel Wi‑Fi, LiDAR, entraînement (TMC2209 + moteur), MPU6050 |
| **MPU6050** | Vecteur gravité live, \|g\|, tangage/roulis, réf. scan, dérive, choc |
| **Diagnostics** | État, ψ, fréquence LiDAR, CRC, file, StallGuard, RSSI |
| **Réglages** | Les 6 paramètres de mise au point, persistés en NVS |
| **OTA** | Téléversement d'un `firmware.bin` ou d'un `littlefs.bin` |

Le balayage **ne démarre plus tout seul** au boot. Après connexion Wi‑Fi, le
scanner reste au repos jusqu'à un clic sur « Lancer le scan » — ou jusqu'à
l'équivalent API. C'est volontaire : sur le terrain on repositionne, on
relance, on ne coupe pas l'alimentation entre deux prises de vue.

## API

Toutes les routes exigent l'authentification HTTP basic.

| Route | Méthode | Corps / query | Effet |
|---|---|---|---|
| `/api/status` | GET | — | Instantané JSON (télémétrie + version) |
| `/api/command?cmd=` | POST | `start` \| `stop` \| `rehome` \| `estop` | File de commandes FreeRTOS |
| `/api/reboot` | POST | — | Redémarrage (refusé pendant balayage ou OTA) |
| `/api/settings` | GET | — | Réglages courants |
| `/api/settings` | POST | formulaire urlencoded | Enregistre + applique |
| `/api/settings?defaults=1` | POST | — | Restaure les valeurs d'usine |
| `/update` | POST | multipart `.bin` | OTA firmware |
| `/updatefs` | POST | multipart `.bin` | OTA LittleFS |
| `/info` | GET | — | Alias de `/api/status` (compat OTA) |

Exemple :

```bash
curl -u admin:lidar-ota -X POST 'http://lidar-scanner.local/api/command?cmd=start'
curl -u admin:lidar-ota http://lidar-scanner.local/api/status
```

### Champs JSON utiles (`/api/status`)

| Champ | Signification |
|---|---|
| `state` | `idle`, `homing`, `scanning`, … |
| `scan_busy` | `true` pendant homing / balayage |
| `hw_wifi_ok`, `rssi`, `ip` | Connexion Wi‑Fi |
| `hw_lidar_ok`, `hw_lidar_warn`, `hw_lidar_crc_pct` | Trames UART + qualité CRC |
| `hw_tmc_ok`, `hw_tmc_version` | Driver TMC2209 sur UART (GPIO 7/15) |
| `hw_motor_enabled` | `EN` actif (false après estop ou OTA) |
| `hw_motor_ok`, `hw_motor_warn` | Homing StallGuard réussi |
| `imu_ok`, `imu_gx/gy/gz`, `imu_has_ref`, `imu_ref_gx/gy/gz` | MPU6050 live + réf. nivellement |
| `imu_tilt_deg`, `imu_shock` | Dérive vs réf. scan, trépied bougé (> 0,3°) |
| `lidar_hz`, `lidar_hz_meas`, `crc_pct` | Consigne / mesure LiDAR, CRC global |
| `sg_live`, `queue_depth` | StallGuard live, file UDP |

## Réglages exposés

| Champ | Bornes | Effet |
|---|---|---|
| `lidar_hz` | 5…13 | Consigne PWM du LiDAR (STL-19P / LD19) |
| `speed` | 0,5…10 °/s | Vitesse d'azimut pendant le balayage |
| `end_deg` | 10…360 ° | Amplitude (180 ° couvre la sphère une fois) |
| `sg` | 1…255 | Seuil StallGuard du homing |
| `i_scan` | 200…1200 mA | Courant RMS en balayage |
| `i_home` | 100…800 mA | Courant RMS en homing |

Les bornes sont appliquées **dans le firmware**, pas seulement dans le
formulaire. Modifier les réglages pendant un balayage est refusé (HTTP 409).

Ce qui **n'y figure pas**, volontairement :

- identifiants Wi‑Fi → portail WiFiManager ;
- calibration géométrique (bras de levier, décalages, gravité) →
  `host/calibration.json`, pour pouvoir rejouer un scan sans rescanner.

## Diagnostic utile sur place

### Matériel (section dédiée)

| Composant | OK | Alerte / Init | Ko |
|---|---|---|---|
| **Wi‑Fi** | Connecté, RSSI affiché | — | Déconnecté |
| **LiDAR** | CRC ≥ 95 %, Hz proche de la consigne | Trames reçues mais CRC ou Hz douteux ; ou démarrage (< 8 s) | Aucune trame UART |
| **Entraînement** | TMC2209 UART OK **et** homing StallGuard réussi | TMC OK, rehome requis | TMC absent (GPIO 7/15) ou driver coupé |
| **MPU6050** | `WHO_AM_I` OK | — | Absent sur I2C (GPIO 8/9) |

### MPU6050 (section dédiée)

| Valeur | Usage |
|---|---|
| **g (live)** | Relever pour `g_zero` dans `calibration.json` (base de niveau) |
| **\|g\|** | Doit rester ≈ 1 g au repos |
| **Tangage / roulis** | Aperçu de l'inclinaison de la base |
| **Réf. scan** | Vecteur mémorisé au nivellement (10 s) en début de balayage |
| **Dérive** | Écart angulaire live vs réf. scan |
| **Choc** | `true` si le trépied a bougé de plus de 0,3° pendant/après scan |

### Télémétrie balayage

| Indicateur | Lecture |
|---|---|
| CRC % | < ~95 % → câblage UART, débit, ou alimentation LiDAR |
| Fréquence mesurée | Doit coller à la consigne ±0,3 Hz |
| StallGuard live | Chute nette à l'approche de la butée ; utile pour régler `sg` |
| File | Monte sans redescendre → Wi‑Fi saturé ou hôte absent |
| RSSI | < −75 dBm → risque de pertes UDP |

## Sécurité

- Même mot de passe que l'OTA ; à changer dans le portail captif.
- Arrêt d'urgence : coupe `EN` du TMC2209 immédiatement.
- Une OTA en cours refuse les commandes de balayage.
- Un balayage en cours refuse l'OTA et le changement de réglages.

Voir aussi [ota.md](ota.md) et [wifi.md](wifi.md).

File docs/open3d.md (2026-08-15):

# Guide Open3D pour le scanner LiDAR

[Open3D](https://www.open3d.org/) est la bibliothèque 3D utilisée par la
station hôte : visualisation pendant le scan, fichiers `.pcd` / `.ply`,
recalage multi-positions et reconstruction de surface.

Ce guide couvre le parcours **typique de ce projet**, pas toute l’API Open3D.

## 1. Installation

```bash
cd host
python -m venv .venv
source .venv/bin/activate   # Windows : .venv\Scripts\activate
pip install -e .
```

Open3D est tiré automatiquement (`open3d>=0.17`). Vérifier :

```bash
python -c "import open3d as o3d; print(o3d.__version__)"
```

### Affichage sous WSL / sans GPU

La fenêtre Open3D a besoin d’un serveur graphique :

| Environnement | Astuce |
|---|---|
| Windows natif | Fonctionne en général sans réglage |
| WSL2 + WSLg | `export DISPLAY=:0` puis `lidar-visualize` |
| WSL2 sans GUI | `lidar-receive … --output scans/test.pcd` puis ouvrir le fichier sous Windows |
| SSH distant | idem : recevoir en `.pcd`, visualiser ailleurs |

Si la fenêtre échoue, `lidar-visualize` bascule tout seul en **réception
sans fenêtre** et écrit un `.pcd` (défaut `scans/headless.pcd`, ou
`--output`). Forcer ce mode : `--headless`.

```bash
# Terminal A (WSL)
lidar-receive --port 9000 --output scans/sim.pcd --auto-stop
# ou
lidar-visualize --port 9000 --headless --output scans/sim.pcd

# Terminal B
lidar-simulate --host 127.0.0.1 --port 9000 --fast
```

Sous Windows (PowerShell), pour ouvrir le fichier généré dans WSL :

```powershell
python -c "import open3d as o3d; o3d.visualization.draw_geometries([o3d.io.read_point_cloud(r'\\wsl$\Ubuntu\home\loret\dev\lidar\host\scans\sim.pcd')])"
```

(Adapter le chemin distro / utilisateur.)

Sans affichage, on peut quand même tout faire sauf la fenêtre live.

## 2. Chaîne complète (vue d’ensemble)

```
ESP32  --UDP polaire-->  host (NumPy)
  ou lidar-simulate
                              │
                              ├─ polar_to_cartesian + calibration.json
                              │
                              ▼
                         points XYZ
                              │
              ┌───────────────┼───────────────┐
              ▼               ▼               ▼
       lidar-visualize   lidar-receive    (rejeu .pcd)
         fenêtre live      fichier.pcd
                              │
                              ▼
                       lidar-register   (plusieurs positions)
                              │
                              ▼
                         lidar-mesh  →  salon.ply
```

### Flux de test sans matériel

Deux terminaux, depuis `host/` avec le venv activé :

```bash
# Terminal A — réception / affichage
lidar-visualize --port 9000

# Terminal B — émetteur synthétique
lidar-simulate --host 127.0.0.1 --port 9000 --fast
```

Sans fenêtre Open3D :

```bash
# Terminal A
lidar-receive --port 9000 --output scans/sim_pos1.pcd --auto-stop

# Terminal B
lidar-simulate --host 127.0.0.1 --port 9000 --fast
```

Le simulateur raytrace une scène axis-aligned. Par défaut **`apartment`** :
salon en L, couloir, baie de porte, canapé, table, bibliothèque, îlot,
colonne. Alternative : `--scene box` (pavé vide).

| Option | Défaut | Rôle |
|---|---|---|
| `--host` / `--port` | `127.0.0.1` / 9000 | Destination |
| `--scene` | `apartment` | `apartment` (L + mobilier) ou `box` |
| `--fast` | off | Ignore le rythme temps réel ~4,5 kpts/s |
| `--psi-end` | 180 | Amplitude azimut |
| `--speed` | 2 °/s | Vitesse azimut (temps réel) |
| `--width` `--depth` `--height` | 5 / 4,5 / 2,6 | Dimensions du salon (m) |
| `--loops` | 1 | `0` = balayages en boucle |
| `--output` | `scans/simulate.pcd` | Nuage XYZ enregistré en fin de scan |
| `--no-save` | off | UDP uniquement, pas de fichier |
| `--no-udp` | off | Fichier uniquement, pas d’émission réseau |
| `--calibration` | `calibration.json` | Appliquée au `.pcd` écrit |

Par défaut, **UDP + fichier** : inutile de lancer `lidar-receive` juste pour
garder le résultat. Avec plusieurs `--loops`, les fichiers sont numérotés
(`simulate_01.pcd`, …).

On doit voir des **murs plans** et des **angles droits**. Si ce n’est pas le
cas avec le simulateur, le bug est côté hôte (calibration / transform), pas
côté matériel.

Open3D intervient dès qu’il y a **affichage**, **fichier nuage** ou
**géométrie** (ICP, Poisson). Le décodage UDP et la trigonométrie restent en
NumPy (`protocol.py`, `transform.py`).

## 3. Visualisation pendant le scan

Sur la station hôte, **avant** de lancer le balayage depuis le panneau web :

```bash
cd host && source .venv/bin/activate
lidar-visualize --port 9000
```

Options utiles :

| Option | Défaut | Rôle |
|---|---|---|
| `--port` | 9000 | Doit coller à l’UDP configuré sur l’ESP32 |
| `--calibration` | `calibration.json` | Bras de levier, offsets, `g_zero` |
| `--refresh` | 0,25 s | Fréquence de rafraîchissement de la fenêtre |
| `--output` | — | Si présent, enregistre un `.pcd` à la fermeture |

### Ce que montre la fenêtre

- Nuage coloré **selon l’altitude Z** (sol / murs / plafond lisibles d’un coup)
- Repère XYZ de 50 cm à l’origine (centre optique)
- Fond sombre, points de taille 1,5

### Navigation (souris)

| Action | Effet |
|---|---|
| Clic gauche + glisser | Orbit autour du nuage |
| Molette | Zoom |
| Clic molette / droit + glisser | Pan (selon version / OS) |
| `R` (souvent) | Reset de la vue — sinon fermer et relancer |

La première arrivée de points recentre la caméra automatiquement.

### Que surveiller en live

| Observation | Cause probable | Action |
|---|---|---|
| Murs **courbes** / cintrage | Bras de levier `tx,ty,tz` faux | [calibration.md](calibration.md) |
| Pièce **penchée** | Trépied / `g_zero` | Relever `g` sur le panneau web → [calibration.md](calibration.md) § 4 |
| Angles muraux non droits | Offset ψ / θ | Calibration angulaire |
| Bande manquante au nadir | Normal (ombre de la base) | Deuxième position |
| Nuage vide | Mauvais port, mauvais Wi‑Fi, hôte mal adressé | Panneau web + `docs/wifi.md` |

Fermer la fenêtre (ou Ctrl+C) pour quitter. Avec `--output`, le nuage est
écrit à ce moment-là.

## 4. Enregistrer un scan en `.pcd`

Sans fenêtre, ou en parallèle d’une autre machine :

```bash
mkdir -p scans
lidar-receive --port 9000 --output scans/salon_pos1.pcd --auto-stop
```

`--auto-stop` s’arrête quand l’ESP32 envoie le drapeau de **fin de balayage**.
Sans cette option : Ctrl+C pour couper.

Le fichier `.pcd` est un nuage Open3D standard (coordonnées en **mètres**,
repère projet après calibration).

### Relire un fichier dans Open3D (sans le scanner)

```bash
python - <<'PY'
import open3d as o3d
p = o3d.io.read_point_cloud("scans/salon_pos1.pcd")
print(p)
o3d.visualization.draw_geometries([p], window_name="Rejeu scan")
PY
```

Ou avec le même coloriage altitude que l’outil live :

```bash
python - <<'PY'
import numpy as np, open3d as o3d
from lidar_host.visualize import colorize_by_height

p = o3d.io.read_point_cloud("scans/salon_pos1.pcd")
pts = np.asarray(p.points)
p.colors = o3d.utility.Vector3dVector(colorize_by_height(pts))
o3d.visualization.draw_geometries(
    [p, o3d.geometry.TriangleMesh.create_coordinate_frame(0.5)],
    window_name="Rejeu coloré",
)
PY
```

## 5. Plusieurs positions : recalage (`lidar-register`)

Pour une pièce complète, on scanne depuis 2–4 emplacements (recouvrement
≈ 30 %), puis :

```bash
lidar-register scans/salon_pos1.pcd scans/salon_pos2.pcd scans/salon_pos3.pcd \
  --output scans/salon_complet.pcd \
  --voxel 0.05
```

Sous le capot Open3D :

1. Sous-échantillonnage voxel (défaut **5 cm**)
2. Estimation de normales
3. **ICP point-to-plane** entre chaque nouvelle position et le nuage fusionné
4. Fusion (`+`) puis écriture `.pcd`

La console affiche `fitness` et `rmse` par position :

| `fitness` | Lecture |
|---|---|
| \> 0,5 | Recouvrement correct |
| 0,3 – 0,5 | Limite — vérifier le chevauchement |
| \< 0,3 | Échec probable — rescaner avec plus de mur commun |

`--voxel` plus petit (ex. `0.02`) affine le recalage mais coûte plus cher en
CPU. Plus grand (`0.08`) : plus robuste / plus grossier.

## 6. Maillage (`lidar-mesh`)

```bash
lidar-mesh scans/salon_complet.pcd --output scans/salon.ply --depth 8 --voxel 0.01
```

Étapes Open3D :

1. Nettoyage : voxel + rejet des outliers statistiques  
2. Normales + orientation cohérente  
3. **Poisson surface reconstruction** (`depth` = niveau octree)  
4. Élagage des zones de faible densité  
5. Export `.ply` (maillage triangulaire)

| `--depth` | 8 | Niveau octree Poisson |
| `--voxel` | 0,01 | Sous-échantillonnage avant Poisson (m) |
| `--smooth` | `taubin` | `none` / `taubin` / `laplacian` / `simple` |
| `--smooth-iter` | 10 | Itérations de lissage |

**Lisser un `.ply` déjà produit** (sans refaire Poisson) :

```bash
lidar-mesh scans/simulate.ply --output scans/simulate_smooth.ply --smooth taubin --smooth-iter 20
```

| Méthode | Effet |
|---|---|
| `taubin` | Lisse en préservant mieux le volume — **recommandé** |
| `laplacian` | Plus agressif, peut « fondre » les arêtes |
| `simple` | Moyenne locale rapide |
| `none` | Pas de lissage |

Trop d’itérations efface les détails (plinthes, arêtes de meubles). Partir de
10–20 pour un intérieur.

Le `.ply` s’ouvre dans Open3D, Blender, MeshLab, CloudCompare, etc. :

```bash
python - <<'PY'
import open3d as o3d
m = o3d.io.read_triangle_mesh("scans/salon.ply")
m.compute_vertex_normals()
o3d.visualization.draw_geometries([m], mesh_show_back_face=True)
PY
```

## 7. Formats et unités

| Format | Contenu | Usage dans ce projet |
|---|---|---|
| `.pcd` | Nuage de points | Sortie `receive` / `register` / `visualize --output` |
| `.ply` | Maillage (ou nuage) | Sortie `mesh` |
| UDP brut | Polaire | Jamais un fichier Open3D — reste sur le fil |

- Distances Open3D : **mètres**  
- Origine : centre optique du STL-19P (après bras de levier)  
- **Z** : vertical après redressement `g_zero` (vers le haut une fois nivelé ; le vecteur gravité de calage est `(0,0,-1)` dans le fichier de config)

Modifier `calibration.json` puis **rejouer** un enregistrement n’est pas automatisé
par une commande dédiée : il faut soit rescanner, soit écrire un petit script
qui relit des paquets bruts. En pratique on corrige la calage, puis on
rescane une position de contrôle — ou on garde les `.pcd` déjà transformés et
on n’y touche plus.

Pour itérer sur la géométrie **sans** matériel, le plus simple est de garder
des captures UDP brutes (extension future) ; aujourd’hui le flux standard est
UDP → XYZ → `.pcd`.

## 8. Recettes Open3D utiles (hors CLI)

À lancer depuis `host/` avec le venv activé.

### Stats d’un nuage

```python
import open3d as o3d
import numpy as np

p = o3d.io.read_point_cloud("scans/salon_pos1.pcd")
pts = np.asarray(p.points)
print(len(pts), "points")
print("bbox min", pts.min(0))
print("bbox max", pts.max(0))
print("étendue m", pts.ptp(0))
```

### Filtrer à la main

```python
import open3d as o3d

p = o3d.io.read_point_cloud("scans/salon_pos1.pcd")
p = p.voxel_down_sample(0.02)
p, _ = p.remove_statistical_outlier(nb_neighbors=20, std_ratio=2.0)
o3d.io.write_point_cloud("scans/salon_pos1_clean.pcd", p)
```

(`lidar-mesh` fait déjà ce nettoyage avant Poisson.)

### Comparer deux positions avant recalage

```python
import open3d as o3d

a = o3d.io.read_point_cloud("scans/salon_pos1.pcd")
b = o3d.io.read_point_cloud("scans/salon_pos2.pcd")
a.paint_uniform_color([1, 0.3, 0.1])
b.paint_uniform_color([0.2, 0.5, 1])
o3d.visualization.draw_geometries([a, b])
```

Si les deux pièces se superposent mal **avant** ICP, augmenter le
recouvrement au prochain scan plutôt que de forcer `--voxel`.

## 9. Débit et performance

| Situation | Conseil |
|---|---|
| Visualisation saccadée | Augmenter `--refresh` (ex. 0,5) |
| PC lent pendant ICP | `--voxel 0.06` ou plus |
| Poisson très long | baisser `--depth`, ou voxel plus gros en entrée |
| Trop de points (> 2 M fusionnés) | voxel avant register / mesh |

Le firmware envoie ~5 000 pts/s ; un scan 90 s ≈ **450 k points**. Open3D
gère ça sans peine sur une machine récente.

## 10. Dépannage Open3D

| Symptôme | Piste |
|---|---|
| `ImportError: libGL` / pas de fenêtre | GPU / WSLg / pilotes ; utiliser `lidar-receive` |
| Fenêtre noire, 0 points | Pas de trafic UDP — IP hôte dans le portail Wi‑Fi, même LAN, port 9000 |
| `.pcd` vide | Scan arrêté trop tôt, ou tout filtré (`rho_min` / intensité) |
| Maillage « boule de savon » | Trous trop grands, depth trop bas, ou normales inversées — rescaner les angles morts |
| ICP qui décale tout | Recouvrement insuffisant entre positions |
| Couleurs absentes dans un viewer tiers | Normal : beaucoup de `.pcd` du projet sont XYZ seuls ; le coloriage altitude est surtout live |

## 11. Liens

| Document | Contenu |
|---|---|
| [host/README.md](../host/README.md) | Installation et commandes CLI |
| [operation.md](operation.md) | Conduite d’un scan sur site |
| [calibration.md](calibration.md) | Bras de levier, offsets, gravité |
| [architecture.md](architecture.md) | Protocole UDP v2 |
| [Open3D docs](https://www.open3d.org/docs/latest/) | Référence amont |

En une phrase : **Open3D est l’atelier 3D du PC** — l’ESP32 livre les
mesures, NumPy les place dans l’espace, Open3D les montre, les fusionne et les
transforme en surface.

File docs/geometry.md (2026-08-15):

# Géométrie et transformation des coordonnées

Ce document justifie l'architecture retenue et donne la transformation exacte
utilisée pour convertir les mesures brutes en nuage de points cartésien.
C'est le cœur mathématique du projet : une erreur ici ne produit pas du bruit,
elle produit un nuage **cohérent mais faux**, ce qui est bien plus difficile à
détecter après coup.

## 1. Principe du balayage

Le LD19 désigne ici la **famille de capteurs** (protocole UART commun). Le
prototype utilise la variante **STL-19P** (FHL-LD19P, 5 000 Hz, détection
verre, 3 oreilles M2,5).

Le LD19 est un LiDAR **2D** : il mesure une distance $\rho$ dans un plan, en
tournant sur 360° autour de son propre axe. Pour obtenir un volume 3D, il faut
déplacer ce plan.

L'architecture retenue est la suivante :

- Le LD19 est monté **couché sur la tranche** : son plan de balayage est
  **vertical**.
- L'ensemble tourne autour d'un **axe vertical** (lacet $\psi$), entraîné par
  le NEMA 17.
- Le centre optique du LD19 est placé **sur l'axe de rotation**.

```
            plan de balayage (vertical, tourne avec la tête)
                        │
              ╔═════════╪═════════╗
              ║         │         ║
              ║      ┌──┴──┐      ║   LD19 couché : son axe de rotation
              ║      │LD19 │      ║   propre est HORIZONTAL
              ║      └──┬──┘      ║
              ╚═════════╪═════════╝
                        │  axe de lacet psi (vertical)
                     ───┼───
                     colonne
                        │
                     trépied
```

### Pourquoi pas l'inclinaison d'un plan horizontal ?

L'approche intuitive — poser le LD19 à plat et basculer le plan autour d'un axe
horizontal — est nettement inférieure :

| Critère | Basculement d'un plan horizontal | Lacet d'un plan vertical |
|---|---|---|
| Pôles d'échantillonnage | Deux points horizontaux arbitraires, sur des murs | Zénith et nadir |
| Densité sur les murs | Très inégale | Uniforme |
| Couple moteur | Varie avec l'angle (gravité) | Constant, frottement seul |
| Fléchissement mécanique | Variable pendant le scan | Statique |
| Alignement avec la gravité | Indirect | L'axe EST la verticale |

Tous les plans de balayage contiennent l'axe de rotation. Ce sont donc des
grands cercles passant par les deux pôles. Avec un axe vertical, ces pôles sont
le zénith et le nadir : le nadir est de toute façon masqué par le trépied, et
la sur-densité au zénith est sans conséquence. Avec un axe horizontal, les
pôles tombent sur deux murs au hasard, où l'on récolte deux taches
hyper-denses entourées de zones clairsemées.

**Conséquence pratique** : puisque le plan à $\psi$ et le plan à $\psi + 180°$
sont le même plan, un balayage de **180° suffit** à couvrir la sphère complète
exactement une fois.

## 2. Rôle des angles

| Symbole | Origine | Rôle | Plage |
|---|---|---|---|
| $\rho$ | LD19 | Distance mesurée | 0,02 – 12 m |
| $\theta$ | LD19 (angle interne) | **Élévation** | 0 – 360° |
| $\psi$ | Moteur pas-à-pas | **Azimut** | 0 – 180° |

C'est le point contre-intuitif : l'angle rapide du LiDAR est l'élévation, et
l'angle lent du moteur est l'azimut. L'inverse produirait un nuage faux.

## 3. Transformation exacte

Dans son propre repère, le LD19 émet dans son plan de balayage. Une fois couché
de sorte que ce plan soit le plan $XZ$, la direction du faisceau est :

$$
\mathbf{u}(\theta) = (\cos\theta,\; 0,\; \sin\theta)
$$

La tête tourne ensuite de $\psi$ autour de l'axe $Z$ :

$$
R_z(\psi) =
\begin{pmatrix}
\cos\psi & -\sin\psi & 0 \\
\sin\psi & \cos\psi & 0 \\
0 & 0 & 1
\end{pmatrix}
$$

D'où, pour un centre optique parfaitement sur l'axe :

$$
\boxed{\;
X = \rho \cos\psi \cos\theta, \quad
Y = \rho \sin\psi \cos\theta, \quad
Z = \rho \sin\theta
\;}
$$

Ce sont exactement les coordonnées sphériques usuelles, à condition de bien
poser **azimut $= \psi$** et **élévation $= \theta$**.

### L'erreur à ne pas commettre

Une spécification naïve écrit souvent :

$$
X = \rho \cos\phi \cos\theta, \quad
Y = \rho \cos\phi \sin\theta, \quad
Z = \rho \sin\phi
$$

en prenant $\theta$ (LiDAR) pour l'azimut et $\phi$ (moteur) pour l'élévation.
Cette formule décrit une **rotule pan-tilt à faisceau unique**, pas un plan de
balayage que l'on fait pivoter.

Contre-exemple immédiat : à $\phi = 90°$, elle donne $(0, 0, \rho)$ pour *tous*
les points — le scan entier s'effondre au zénith. En réalité, un LiDAR 2D
incliné à 90° balaie toujours un cercle complet. L'erreur croît continûment
avec $\phi$ et déforme l'intégralité du nuage.

## 4. Correction du bras de levier

En pratique le centre optique n'est jamais exactement sur l'axe. Soit
$\mathbf{t} = (t_x, t_y, t_z)$ le vecteur allant de l'axe de rotation au centre
optique, exprimé dans le repère de la tête. La transformation devient :

$$
\mathbf{p} = R_z(\psi) \cdot \big( \rho\,\mathbf{u}(\theta) + \mathbf{t} \big)
$$

soit, en développant :

$$
\begin{aligned}
X &= \cos\psi\,(\rho\cos\theta + t_x) - \sin\psi\,t_y \\
Y &= \sin\psi\,(\rho\cos\theta + t_x) + \cos\psi\,t_y \\
Z &= \rho\sin\theta + t_z
\end{aligned}
$$

**Pourquoi c'est important** : le boîtier du STL-19P fait **54 × 46 mm**
(oreilles comprises). Un décalage résiduel de 20 à 30 mm est du même ordre que
la précision du capteur (±45 mm). Mais contrairement au bruit, cette erreur est
**systématique** : elle ne se moyenne pas, elle courbe légèrement les murs et
fausse les angles.

Le berceau est conçu pour amener $\mathbf{t}$ aussi près de zéro que possible.
Le résidu se mesure et se compense en post-traitement : voir
[calibration.md](calibration.md).

## 5. Redressement selon la gravité

L'axe de lacet n'est vertical que si le trépied est de niveau. Le MPU6050,
solidaire de la **base fixe**, mesure le vecteur gravité au repos :

$$
\mathbf{g} = (g_x, g_y, g_z)
$$

On construit la rotation $R_{\text{level}}$ qui amène $\mathbf{g}$ sur
$(0, 0, -1)$, et on l'applique au nuage entier :

$$
\mathbf{p}_{\text{monde}} = R_{\text{level}} \cdot \mathbf{p}
$$

Une seule mesure statique, moyennée sur quelques secondes, suffit — et c'est
justement le régime où un MPU6050 est précis.

### Ce qu'il ne faut PAS faire

Injecter la mesure d'inclinaison de l'IMU **point par point** dans $\psi$ ou
$\theta$. Le bruit d'un MPU6050 est de 0,5 à 1° :

| Distance | Erreur induite par 1° |
|---|---|
| 2 m | 35 mm |
| 5 m | 87 mm |
| 10 m | 175 mm |

À comparer aux 0,1125° par micro-pas du moteur en 1/16, et aux ±45 mm du LD19.
L'IMU dégraderait la mesure d'un facteur 2 à 4. Le moteur est la référence
angulaire ; l'IMU sert au **nivellement** et à la **détection de choc**.

## 6. Résolution et durée de scan

Le STL-19P échantillonne à **5 000 Hz** quelle que soit sa vitesse de rotation,
elle-même réglable de 5 à 13 Hz par PWM. Sur trépied le temps n'est pas
critique : **descendre à 5 Hz double la densité angulaire gratuitement**.

| Vitesse STL-19P | Points / tour | Résolution en $\theta$ | Tour |
|---|---|---|---|
| 10 Hz (défaut) | 500 | 0,72° | 100 ms |
| 5 Hz | 1 000 | 0,36° | 200 ms |

Pour un balayage de 180° en azimut :

| Pas en $\psi$ | Tranches | Points (à 5 Hz) | Durée |
|---|---|---|---|
| 0,8° | 225 | 225 000 | 45 s |
| 0,4° | 450 | 450 000 | 90 s |
| 0,2° | 900 | 900 000 | 180 s |

Espacement des points à 5 m avec un pas de 0,4° : environ **35 mm** dans les
deux directions.

## 7. Budget d'erreur

| Source | Contribution | Nature |
|---|---|---|
| Précision LD19 | ±45 mm (0,3–12 m) | Aléatoire |
| Bras de levier non compensé | jusqu'à 30 mm | **Systématique** |
| Micro-pas moteur (1/16) | 0,11° → 10 mm à 5 m | Systématique, répétable |
| Jeu des roulements | < 0,05° | Aléatoire |
| Défaut de nivellement | 0,2° après réglage IMU | Systématique, corrigeable |
| Décalage temporel $\rho$ / $\psi$ | voir ci-dessous | Systématique |

**Réalisme** : environ ±5 cm sur un mur, pour un espacement de points de 3 à
7 cm. Excellent pour un plan d'étage ou un relevé volumétrique ; insuffisant
pour du BIM de détail, où un scanner professionnel donne ±2 mm.

### Décalage temporel

Le LD19 émet des trames de 12 points horodatées côté capteur. Si le moteur
avance en continu pendant l'émission d'une trame, tous les points d'une trame
ne partagent pas le même $\psi$. Deux stratégies :

1. **Pas à pas discret** — le moteur s'arrête à chaque tranche, on capture un
   tour complet, puis on avance. Aucune ambiguïté, mais plus lent et les
   accélérations sollicitent la mécanique.
2. **Balayage continu** — le moteur tourne lentement et régulièrement, et on
   interpole $\psi$ à l'horodatage de chaque point. Plus rapide, plus doux, et
   l'échantillonnage devient hélicoïdal.

Le firmware retient la seconde approche : $\psi$ est interpolé linéairement
entre deux jalons de position moteur, à partir de l'horodatage du point.

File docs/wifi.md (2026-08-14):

# Configuration WiFi (WiFiManager)

Le firmware utilise [WiFiManager](https://github.com/tzapu/WiFiManager) : pas de SSID/mot de passe codés en dur. Les credentials sont stockés en flash NVS.

## Premier démarrage

1. Flasher l'**amorce** en USB (`pio run -e seed -t upload`) et alimenter
   l'ESP32-S3.
2. L'ESP32 tente de se connecter au WiFi sauvegardé ; s'il n'y en a pas (ou échec), il ouvre un **point d'accès** :
   - SSID AP : `LiDAR-Scanner-Setup`
   - Mot de passe : aucun (AP ouvert par défaut)
3. Depuis un téléphone ou un PC, se connecter à cet AP.
4. Le portail captif s'ouvre (ou naviguer vers `192.168.4.1`).
5. Renseigner :
   - **SSID** et **mot de passe** du réseau local
   - **IP station hôte (UDP)** : adresse IP du PC qui reçoit le nuage de points (ex. `192.168.1.100`)
6. Valider — l'ESP32 redémarre et se connecte au WiFi.

## Démarrages suivants

Connexion automatique avec les paramètres sauvegardés. L'IP UDP hôte est également persistée.

## Réinitialiser le WiFi

Maintenir le bouton **BOOT** (GPIO 0) enfoncé **pendant la mise sous tension** :

- Les credentials WiFi et l'IP UDP sont effacés.
- Au prochain boot, le portail de configuration réapparaît.

## Paramètres (`config.h`)

| Constante | Défaut | Description |
|---|---|---|
| `WIFIMANAGER_AP_NAME` | `LiDAR-Scanner-Setup` | Nom du point d'accès |
| `WIFIMANAGER_AP_PASSWORD` | *(vide)* | Mot de passe AP ; vide = ouvert |
| `WIFIMANAGER_PORTAL_TIMEOUT_S` | 180 | Timeout portail (s) |
| `UDP_HOST_DEFAULT` | `192.168.1.100` | IP hôte par défaut dans le portail |

## Dépannage

| Symptôme | Action |
|---|---|
| Portail ne s'ouvre pas | Reset WiFi (BOOT au boot), vérifier serial monitor |
| Connexion OK mais pas de points | Vérifier `IP station hôte` = IP du PC sur le même réseau |
| PC derrière firewall | Autoriser UDP entrant port 9000 |
| Changement de box / SSID | Reset WiFi et reconfigurer |

## Serial monitor

```
[lidar-scanner] amorce OTA 0.1.0-seed
[wifi] connexion, sinon portail AP « LiDAR-Scanner-Setup »
[wifi] connecté — IP 192.168.1.42
[seed] http://lidar-scanner.local/ ou http://192.168.1.42/
```

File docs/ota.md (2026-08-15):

# Mise à jour par le réseau (OTA)

Le scanner se met à jour par Wi-Fi, sans câble USB. C'est particulièrement
utile une fois l'appareil sanglé sur son trépied, port USB tourné vers
l'intérieur du boîtier.

Le **premier** flash se fait en USB avec l'amorce (`pio run -e seed -t upload`).
Elle n'initialise ni le LiDAR ni le moteur : uniquement le Wi-Fi, ArduinoOTA
et la page web. Les mises à jour suivantes — firmware **et** filesystem
LittleFS — passent par le réseau. Le redémarrage à distance est aussi
disponible depuis le panneau (**Redémarrer**, `POST /api/reboot`) hors
balayage.

Deux voies coexistent ensuite :

| Voie | Port | Usage |
|---|---|---|
| **espota** | 3232 | Développement : `pio run -e ota -t upload` / `-t uploadfs` |
| **Page web** | 80 | Terrain : déposer `firmware.bin` ou `littlefs.bin` |

## 1. Prérequis : schéma de partitions

L'OTA écrit le nouveau firmware dans une **seconde partition applicative**,
puis bascule le pointeur de démarrage. Il faut donc un schéma de partitions qui
en comporte deux.

`default_16MB.csv`, déjà configuré, fournit `app0` et `app1` de 6,5 Mo chacune,
plus une partition `data` utilisée comme LittleFS.

Le firmware le vérifie au démarrage et le signale sur le port série :

```
[ota] partition active « app0 »
[ota] cible de mise à jour « app1 » (6400 ko)
```

Si l'on lit `[ota] ERREUR : aucune seconde partition applicative`, c'est que
`board_build.partitions` a été modifié. L'OTA est alors désactivé, mais le
scanner fonctionne normalement.

## 2. Mot de passe

Il se configure dans le **portail WiFiManager**, à côté de l'adresse de la
station hôte, et il est persisté en NVS.

Valeur de repli au premier démarrage : `lidar-ota`. Le firmware le rappelle
au démarrage :

```
[wifi] ATTENTION : mot de passe OTA laissé par défaut
```

Le même mot de passe protège les deux voies. Pour la page web, il s'agit d'une
authentification HTTP basic avec l'identifiant **`admin`**.

> Sans mot de passe, n'importe qui sur le réseau local peut reflasher
> l'appareil. Le changer prend dix secondes dans le portail.

## 3. Mise à jour depuis PlatformIO

```bash
cd firmware
pio run -e ota -t upload      # firmware scanner
pio run -e ota -t uploadfs    # image LittleFS (contenu de data/)
```

L'amorce elle-même se met à jour avec `-e seed-ota` à la place de `-e ota`.

L'environnement `ota` de `platformio.ini` vise `lidar-scanner.local`. Si mDNS
ne résout pas sur votre réseau — c'est fréquent sous Windows et sur certains
réseaux invités — passer l'adresse IP directement :

```bash
pio run -e ota -t upload --upload-port 192.168.1.42
```

Le mot de passe est dans `upload_flags` (`--auth=`). Le corriger s'il a été
changé dans le portail.

Le port série n'est évidemment pas disponible par cette voie. Pour suivre les
journaux à distance, garder l'USB branché pour le moniteur et n'utiliser l'OTA
que pour le téléversement.

## 4. Mise à jour depuis un navigateur

Ouvrir `http://lidar-scanner.local/` — ou l'adresse IP — et s'authentifier avec
`admin` et le mot de passe OTA.

La section **Mise à jour OTA** de la page (voir aussi [web.md](web.md)) propose
deux dépôts : `firmware.bin` (partition applicative) et `littlefs.bin`
(partition data). Une barre de progression suit l'écriture, puis redémarrage.

Binaires produits par la compilation :

```
firmware/.pio/build/usb/firmware.bin
firmware/.pio/build/usb/littlefs.bin
```

C'est bien `firmware.bin` / `littlefs.bin` qu'il faut, **pas** `firmware.elf`
ni `firmware.factory.bin`.

### Points d'accès

| Route | Méthode | Rôle |
|---|---|---|
| `/` | GET | Page de mise à jour |
| `/info` | GET | État en JSON : version, partitions, mémoire, occupation |
| `/api/reboot` | POST | Redémarrage ESP32 (refusé pendant balayage ou OTA) |
| `/update` | POST | Téléversement multipart du firmware |
| `/updatefs` | POST | Téléversement multipart du filesystem LittleFS |

## 5. Sécurité mécanique

Une mise à jour arrête le moteur **avant** d'écrire quoi que ce soit en flash.
Sans cette précaution, l'ESP32 redémarrerait avec le TMC2209 encore alimenté,
laissant l'axe en couple pendant plusieurs secondes.

Séquence exécutée au démarrage d'une mise à jour :

1. `ota_lock` posé : plus aucun balayage ne peut démarrer.
2. `scannerEmergencyStop()` : broche `EN` du TMC2209 relâchée, moteur libre.
3. Suspension des tâches LiDAR et réseau, qui libèrent CPU et bande passante.
4. Écriture en flash, puis redémarrage.

### L'OTA est refusé pendant un balayage

Flasher en pleine acquisition perdrait le scan en cours et laisserait la
mécanique dans un état indéterminé. Tant que l'état est `Homing`, `Spinup` ou
`Scanning` :

- ArduinoOTA n'est pas servi — le port 3232 ne répond simplement pas ;
- la page web reste accessible et affiche « balayage en cours », et
  `/update` renvoie **503**.

Un balayage dure au plus 180 s. Pour passer outre, mettre
`OTA_ALLOW_DURING_SCAN` à 1 dans `config.h` — en connaissance de cause.

### Le scanner démarre au repos

Plus de balayage automatique au boot : `motion_task` attend une commande
(`start` depuis le panneau web). L'OTA est donc joignable immédiatement après
la connexion Wi‑Fi, sans fenêtre artificielle de 10 s. Un firmware qui planterait
*pendant* un scan reste rattrapable au redémarrage suivant, puisque le prochain
boot ne relance rien tout seul.

La constante `OTA_BOOT_WINDOW_S` dans `config.h` est conservée pour une
éventuelle réactivation d'un démarrage automatique, mais n'est plus utilisée.

## 6. Comportement en cas d'échec

| Cas | Réaction |
|---|---|
| Mot de passe erroné | Refus avant toute écriture ; rien n'est touché |
| Balayage en cours | Refus, code 503 |
| Coupure en cours d'écriture | Redémarrage automatique sur l'**ancienne** partition |
| Binaire corrompu | `Update.end()` échoue, la bascule n'a pas lieu |

La partition en cours d'exécution n'est jamais écrasée : l'écriture se fait
toujours dans l'autre. Une mise à jour interrompue laisse donc l'ancien
firmware intact et bootable. C'est la propriété fondamentale du mécanisme, et
la raison pour laquelle un `.bin` mal formé ne brique pas l'appareil.

Après un échec autre qu'une erreur d'authentification, le firmware redémarre
de lui-même : la flash pouvant être partiellement écrite, un état propre vaut
mieux qu'un état indéterminé.

## 7. Récupération

Si l'OTA devient inaccessible — mauvaise configuration Wi-Fi, plantage
précoce — il reste toujours l'USB. On reflashe l'amorce (page OTA seule)
ou directement le firmware scanner :

```bash
cd firmware
pio run -e seed -t upload     # amorce OTA
# ou
pio run -e usb -t upload      # firmware scanner
```

Et pour repartir d'une configuration réseau vierge : maintenir **BOOT** au
démarrage. Cela efface les identifiants Wi-Fi, l'adresse de la station hôte et
le mot de passe OTA, et rouvre le portail captif.

## 8. Dépannage

| Symptôme | Cause probable | Correction |
|---|---|---|
| `lidar-scanner.local` introuvable | mDNS non résolu | Utiliser l'adresse IP |
| espota expire | Balayage en cours | Attendre la fin, ou redémarrer (boot au repos) |
| `Authentication Failed` | Mot de passe divergent | Aligner `--auth=` sur la valeur du portail |
| La page demande sans cesse le mot de passe | Identifiant oublié | L'identifiant est `admin` |
| `Not Enough Space` | Schéma sans OTA | Rétablir `default_16MB.csv` |
| Redémarre sur l'ancienne version | Écriture incomplète | Vérifier le Wi-Fi, réessayer |
| Coupure à mi-parcours, systématique | Alimentation limite | Brancher sur secteur plutôt que power bank |

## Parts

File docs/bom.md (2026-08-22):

# Nomenclature (BOM)

## A. Déjà commandé

| Réf | Composant | Qté utilisée | Qté au panier | Rôle |
|---|---|---|---|---|
| A1 | LiDAR STL-19P (FHL-LD19P, youyeetoo) | 1 | 1 | Mesure de distance, 360°, détection verre |
| A2 | ESP32-S3 DevKitC-1 (N16R8) | 1 | 3 | Acquisition, pilotage, Wi-Fi |
| A3 | Driver TMC2209 v2.0 | 1 | 2 | Pilotage moteur, StealthChop2 + StallGuard |
| A4 | Moteur NEMA 17 pas à pas 4 fils (17HS4401) | 1 | 1 | Entraînement STEP/DIR via TMC2209 |
| A5 | MPU6050 (GY-521) | 1 | 3 | Nivellement, détection de choc |
| A6 | Roulement 608ZZ (8×22×7) | 2 | 40 | Guidage de l'axe vertical |
| A7 | Insert laiton 1/4"-20 UNC **× 10 × 8 mm** | 1 | 50 | Fixation trépied (logement Ø8,4) |
| A8 | Module trigger USB-C PD | 1 | 5 | Extraction du 12 V depuis la power bank |
| A9 | Convertisseur buck 12 V → 5 V 3 A | 1 | 2 | Alimentation ESP32 + LiDAR |
| A10 | Power bank USB-C PD 100 W | 1 | — | Source d'énergie |

Les quantités au panier laissent une marge confortable de rechange, ce qui est
appréciable sur les pièces sensibles au montage (roulements, inserts).

## B. À acquérir en complément

Ces pièces sont indispensables et **ne figurent pas** dans la commande
initiale.

| Réf | Composant | Qté | Prix indicatif | Remarques |
|---|---|---|---|---|
| B1 | Tige acier rectifiée Ø8 h6, longueur ≥ 120 mm | 1 | 3 € | Tige linéaire d'imprimante 3D, à recouper à **115 mm** |
| B2 | Accouplement flexible 5 → 8 mm (Ø19 × 25 mm) | 1 | 4 € | Type mâchoires/araignée. Rigide **déconseillé** : il ferait forcer les roulements en cas de défaut d'alignement |
| B3 | Vis M3×12 (ou vis fournies avec le moteur) + écrou M3 | 4 | — | Moteur sur plateau — **trous traversants** sur la bride NEMA |
| B4 | Vis M3×20 + écrou M3 | 4 | — | Colonne sur plateau |
| B5 | Vis M3×25 + écrou M3 | 1 | — | Serrage du berceau sur la tige |
| B6 | Vis M3×8 | 8 | — | Couvercle du boîtier + modules |
| B7 | Vis M2,5×8 + écrou M2,5 | 3 | — | STL-19P sur le berceau (3 oreilles) |
| B8 | Colliers rilsan 2,5 × 100 mm | 10 | 2 € | Sanglage du boîtier, maintien des câbles |
| B9 | Fil silicone AWG24-26, 4 couleurs | 2 m | 4 € | Câblage interne |
| B10 | Niveau à bulle tubulaire Ø15 (optionnel) | 1 | 3 € | Pré-réglage rapide avant nivellement IMU |

Un assortiment de visserie M3 coûte environ 10 € et couvre B3 à B6.

**Total complémentaire : environ 25 €.**

## C. Pièces imprimées en 3D

Sources paramétriques dans [`mechanical/openscad/`](../mechanical/openscad/),
STL générés dans [`mechanical/stl/`](../mechanical/stl/).

| Réf | Pièce | Qté | Rôle |
|---|---|---|---|
| C0 | `test_fits` | 1 | **Coupon de calibration — à imprimer en premier** |
| C1 | `base_plate` | 1 | Interface trépied, support moteur, embase colonne |
| C2 | `bearing_tower` | 1 | Porte les deux 608ZZ, définit l'axe. Pièce critique |
| C3 | `lidar_cradle` | 1 | Présente le STL-19P sur la tranche (3 oreilles M2,5), serre sur la tige |
| C4 | `electronics_box` | 1 | Boîtier ESP32 / TMC2209 / alimentation |
| C5 | `electronics_lid` | 1 | Couvercle du boîtier |

Consommation : environ 220 g de PETG, 9 h d'impression au total.

## D. Outillage

| Outil | Usage |
|---|---|
| Imprimante 3D (volume ≥ 130 × 130 × 140 mm) | Pièces C1 à C5 |
| Fer à souder à panne large | Pose de l'insert 1/4"-20 |
| Pied à coulisse | Vérification des ajustements et du décalage optique |
| Multimètre | Réglage du Vref du TMC2209 |
| Tournevis de précision plat | Potentiomètre du TMC2209 |
| Scie à métaux ou Dremel | Recoupe de la tige Ø8 |
| Clés Allen 1,5 / 2 / 2,5 mm | Accouplement et visserie |

## E. Points de vigilance à l'achat

**Variante du LD19.** Trois versions circulent sous des noms voisins :

| Modèle | Mesures/s | Portée | Détection du verre |
|---|---|---|---|
| FHL-LD19 | 4 500 | 12 m | Non |
| FHL-LD19P / **STL-19P** | 5 000 | 12 m | Oui |
| FHL-LD19 Plus / STL-27L | 21 600 | 25 m | Oui |

L'exemplaire reçu est le **STL-19P** (FHL-LD19P) : 5 000 Hz, détection du
verre, **3 oreilles M2,5** (pas 4 fentes). Le berceau `lidar_cradle` est
dimensionné pour cette variante. Nappe : **P5V vert**, **GND jaune**,
**TX blanc**, **PWM noir** (voir [wiring.md](wiring.md) § 3).
Voir [operation.md](operation.md) pour les vitres et miroirs.

**Moteur pas à pas obligatoire.** Le châssis et le firmware supposent un NEMA
17 **4 fils** piloté en STEP/DIR par TMC2209. Un moteur brushless BLDC (ex.
42BL3802-23A) est **incompatible** — à remplacer avant tout montage électrique.
Modèles courants : Creality 42-40, STEPPERONLINE 17HE15, ou tout 17HS4401
équivalent. Câble 4 fils : **noir A+**, **bleu A−**, **vert B+**, **rouge B−**
(voir [wiring.md](wiring.md) § 5).

**Trigger PD.** Vérifier que le module retenu délivre bien 12 V et non
seulement 5/9 V. Les modules à DIP switch sont les plus souples.

**Power bank.** Elle doit tenir 12 V sous environ 1 A. Certaines coupent
automatiquement en dessous d'un seuil de consommation : le scanner tire
environ 8 à 12 W en balayage, ce qui suffit à maintenir la plupart des modèles
éveillés. Vérifier néanmoins avant une longue session.

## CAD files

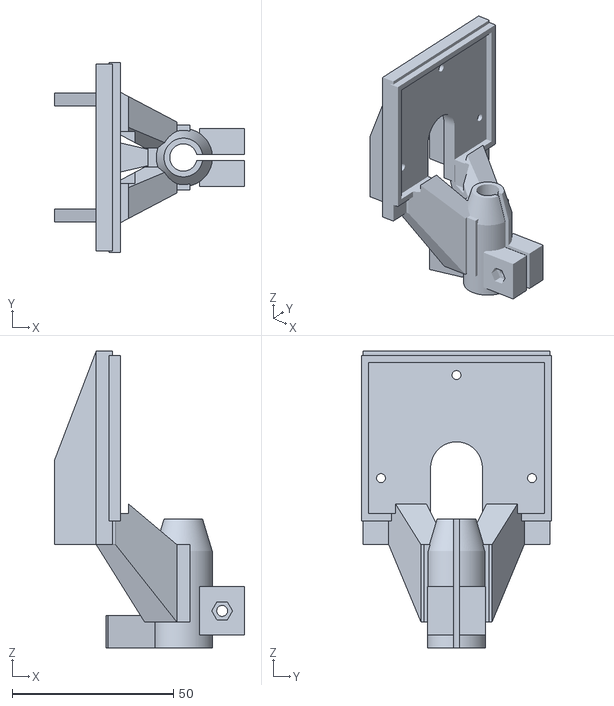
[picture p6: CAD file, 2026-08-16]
mechanical/stl/lidar_cradle.stl
59.0 x 59.0 x 92.0

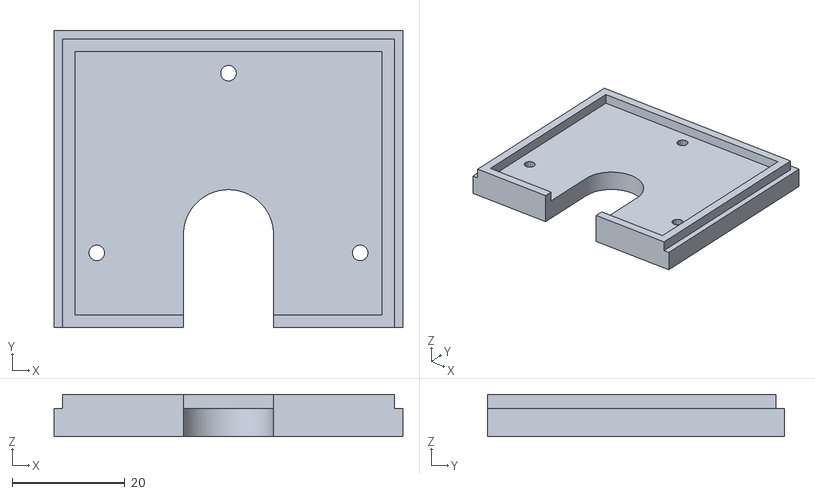
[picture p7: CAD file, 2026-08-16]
mechanical/stl/test_lidar_fit.stl
62.0 x 52.8 x 7.50

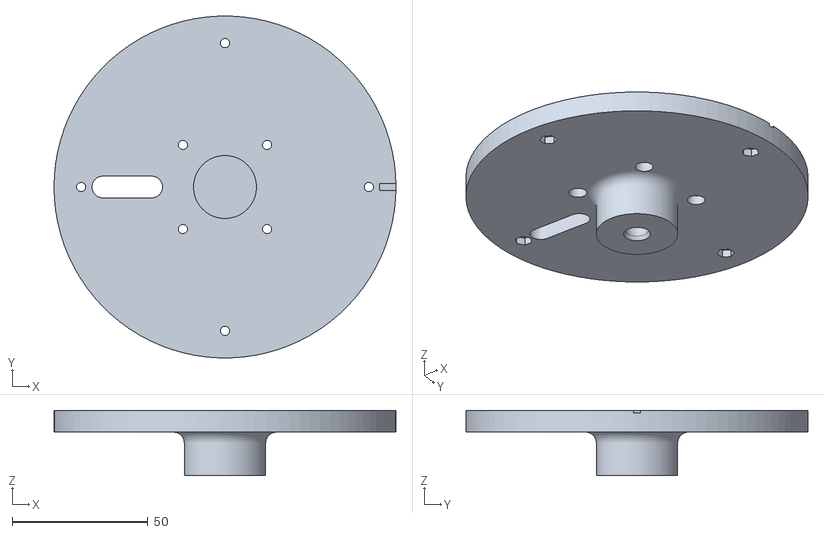
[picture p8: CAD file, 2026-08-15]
mechanical/stl/base_plate.stl
126.0 x 125.9 x 24.0

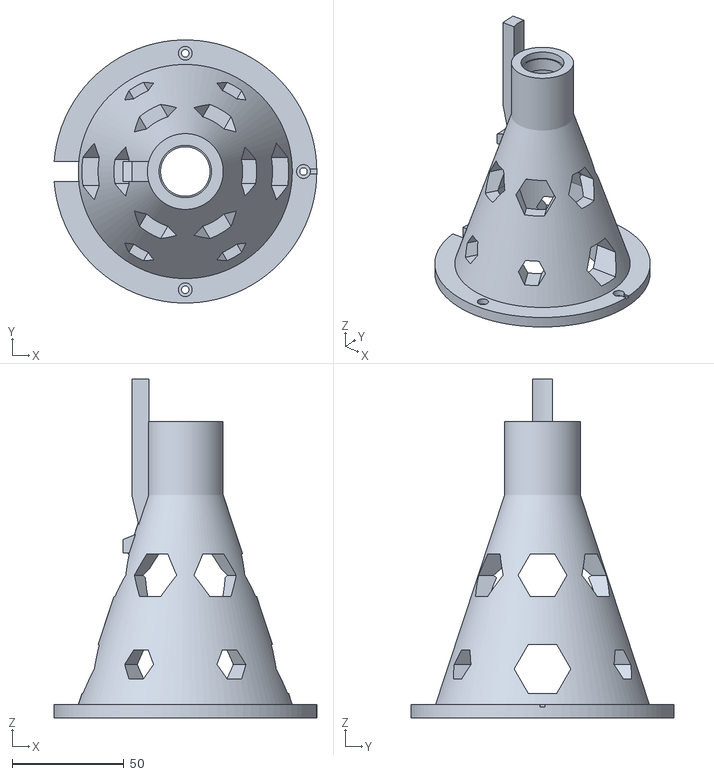
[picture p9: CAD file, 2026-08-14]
mechanical/stl/bearing_tower.stl
117.8 x 117.9 x 152.0

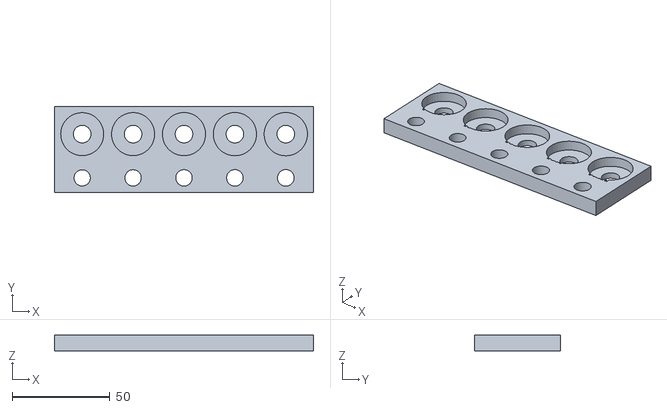
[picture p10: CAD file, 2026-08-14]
mechanical/stl/test_fits.stl
132.3 x 44.0 x 8.00

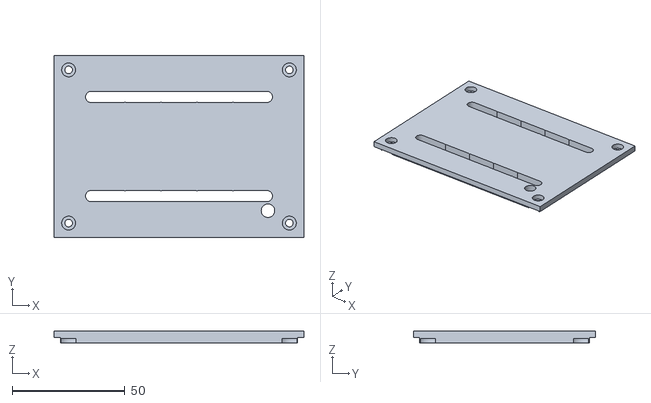
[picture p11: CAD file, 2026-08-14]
mechanical/stl/electronics_lid.stl
111.0 x 81.0 x 5.50

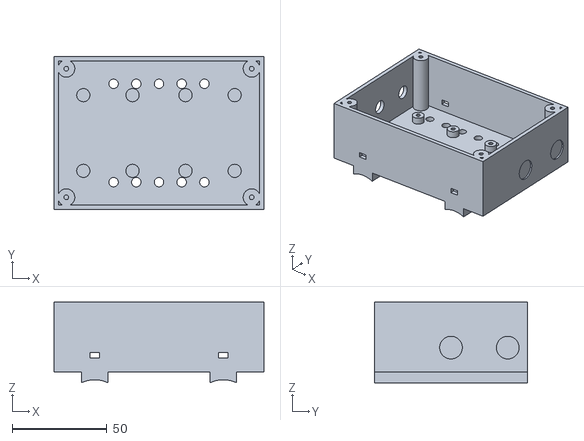
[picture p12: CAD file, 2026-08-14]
mechanical/stl/electronics_box.stl
111.0 x 81.0 x 42.6

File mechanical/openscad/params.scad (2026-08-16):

// ============================================================
//  Scanner 3D LiDAR — paramètres partagés
//  Toutes les cotes sont en millimètres.
//
//  Repère d'assemblage : z = 0 sur la face SUPÉRIEURE du plateau
//  de base. L'axe de rotation (lacet psi) est l'axe Z.
// ============================================================

// Finesse de facettisation adaptative : les petits perçages restent
// légers, les grands diamètres restent lisses.
$fa = 4;
$fs = 0.6;

// ------------------------------------------------------------
//  Ajustements d'impression
//  À recalibrer sur votre imprimante avec mechanical/openscad/
//  test_fits.scad avant d'imprimer les pièces définitives.
// ------------------------------------------------------------
fit_press = 0.15;   // serré   : roulement — encoche 5 du coupon (delta +0,15 → Ø22,15)
fit_slide = 0.45;   // glissant: tige — encoche 4 (delta +0,10 → Ø8,45)
fit_free = 0.50;    // libre   : dégagements

// ------------------------------------------------------------
//  Roulement 608ZZ
// ------------------------------------------------------------
bearing_od = 22;
bearing_id = 8;
bearing_w = 7;

// ------------------------------------------------------------
//  Arbre vertical (tige acier rectifiée Ø8 h6)
// ------------------------------------------------------------
shaft_d = 8;
// Longueur utile : de l'accouplement (z 65) au sommet du moyeu (z 180).
// Ne PAS dépasser 180 : au-delà, la tige pénètre dans le corps du LD19.
shaft_len = 115;

// ------------------------------------------------------------
//  Moteur NEMA 17 (17HS4401)
// ------------------------------------------------------------
nema_body = 42.3;
nema_len = 40;       // longueur du corps (marge : 38 mm réels)
nema_pitch = 31;     // entraxe carré des 4 vis M3
nema_boss_d = 22;    // bossage de centrage
nema_boss_h = 2;
nema_shaft_d = 5;
nema_shaft_l = 24;

// ------------------------------------------------------------
//  Accouplement flexible 5 mm -> 8 mm (type mâchoires / araignée)
// ------------------------------------------------------------
coupler_d = 19;
coupler_l = 25;

// ------------------------------------------------------------
//  LiDAR — STL-19P / FHL-LD19P (LDROBOT, 3 oreilles de fixation)
//  Câble vers le bas au montage sur le berceau.
//  ATTENTION : lidar_optical_offset à VÉRIFIER au pied à coulisse.
//  Voir docs/calibration.md § « Mesure du décalage optique ».
//  Perçage : datasheet STL-19P § 5.1, vue de la face de fixation.
//  Repère : bord des 2 oreilles + connecteur ZH1.5T = bas du berceau.
//  Corps 38,59 × 38,59 ; envergure 54 ; longueur hors-tout 46,29.
//  3 × Φ2,5 通孔, lamage capteur Φ4,46 × 2 (pas sur le berceau).
// ------------------------------------------------------------
lidar_w = 54;                  // envergure Y (2 oreilles)
lidar_h = 46.29;               // longueur Z hors-tout (oreille simple comprise)
lidar_body = 38.59;            // côté du corps, hors oreille simple
lidar_thk = 34.8;              // profondeur X
lidar_optical_offset = 22;     // plan de balayage / face de fixation  <-- À VÉRIFIER
lidar_screw_d = 2.8;           // M2,5 traversant, jeu impression
lidar_hole_y = 23.4;           // 46,8 / 2
// Entraxe vertical paire câble → oreille simple = 31,92 (pas 38,59 = corps)
lidar_hole_span_z = 31.92;
lidar_top_hole_z = 42.69;      // oreille simple, depuis le bord câble
lidar_side_hole_z = lidar_top_hole_z - lidar_hole_span_z;  // 10,77
lidar_cable_w = 16;            // passage nappe : fente dans platine + rebord
lidar_cable_h = 14;            // hauteur depuis le bas du footprint

// ------------------------------------------------------------
//  Visserie M3
// ------------------------------------------------------------
m3_clear = 3.4;
m3_head_d = 6.2;
m3_head_h = 3.2;
m3_nut_af = 5.6;   // entreplat
m3_nut_h = 2.7;

// ------------------------------------------------------------
//  Insert laiton 1/4"-20 UNC (fixation trépied)
// ------------------------------------------------------------
insert_qtr_d = 8.4;
insert_qtr_l = 13;

// ------------------------------------------------------------
//  Plateau de base
// ------------------------------------------------------------
plate_d = 126;
plate_t = 8;
tripod_boss_d = 30;
tripod_boss_h = 16;
tower_bolt_circle = 106;   // hors du cône : têtes de vis accessibles

// ------------------------------------------------------------
//  Colonne à roulements  (z local = 0 sur la face inférieure,
//  qui repose sur la face supérieure du plateau)
// ------------------------------------------------------------
tower_flange_d = 118;
tower_flange_t = 6;
tower_base_d = 96;
tower_top_d = 34;
tower_cone_top_z = 100;   // fin du cône
tower_total_h = 133;      // hauteur totale
tower_cavity_d = 62;      // dégagement moteur (diagonale NEMA 17 = 59.8 mm)
tower_cavity_top_z = 42;
tower_throat_d = 26;      // dégagement accouplement (Ø19)
tower_throat_z = 78;

bearing_lo_z = 82;        // face inférieure du roulement bas
bearing_hi_z = 122;       // face inférieure du roulement haut
bearing_relief_d = 23.5;

// ------------------------------------------------------------
//  Berceau LiDAR  (cotes en repère d'assemblage global)
// ------------------------------------------------------------
hub_d = 18;
hub_z0 = 140;
hub_z1 = 180;
hub_top_d = 12;          // rétreint pour limiter l'occultation au nadir
web_z0 = 176;
web_z1 = 188;
web_hw = 7;              // demi-largeur en Y
plate_x = -22;           // face de fixation du LiDAR (= -lidar_optical_offset)
cradle_plate_t = 5;
optical_z = 205;         // hauteur du centre optique  => centre du nuage

// ------------------------------------------------------------
//  Boîtier électronique
// ------------------------------------------------------------
box_ix = 106;
box_iy = 76;
box_iz = 34;
box_wall = 2.5;

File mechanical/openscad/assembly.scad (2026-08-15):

// ============================================================
//  Vue d'assemblage complète (visualisation uniquement)
//
//  Les pièces achetées (moteur, roulements, accouplement, LiDAR)
//  sont représentées par des volumes simplifiés.
//
//  Rendu :
//    openscad -o assembly.png --imgsize=1200,1400 --camera=... assembly.scad
// ============================================================

include <lib.scad>

use <base_plate.scad>
use <bearing_tower.scad>
use <lidar_cradle.scad>

show_ghost = true;   // pièces du commerce
show_plane = true;   // plan de balayage du LiDAR

// ------------------------------------------------------------
//  Volumes simplifiés des composants achetés
// ------------------------------------------------------------
module ghost_nema17() {
    color("#404448") {
        translate([-nema_body / 2, -nema_body / 2, 0]) cube([nema_body, nema_body, nema_len]);
        translate([0, 0, nema_len]) cylinder(d = nema_boss_d, h = nema_boss_h);
        translate([0, 0, nema_len]) cylinder(d = nema_shaft_d, h = nema_shaft_l);
    }
}

module ghost_bearing() {
    color("#9aa0a6")
        difference() {
            cylinder(d = bearing_od, h = bearing_w);
            translate([0, 0, -0.5]) cylinder(d = bearing_id, h = bearing_w + 1);
        }
}

module ghost_coupler() {
    color("#c0392b") cylinder(d = coupler_d, h = coupler_l);
}

module ghost_shaft() {
    color("#d8dce0") cylinder(d = shaft_d, h = shaft_len);
}

module ghost_lidar() {
    // STL-19P couché : face de fixation contre la platine (x = plate_x)
    color("#2b2f33")
        translate([plate_x, -lidar_w / 2, optical_z - lidar_h / 2])
            cube([lidar_thk, lidar_w, lidar_h]);
    // dôme rotatif, centré sur l'axe optique
    color("#1a1d20")
        translate([-1.5, 0, optical_z]) rotate([0, 90, 0]) cylinder(d = 35.3, h = 3);
}

// ------------------------------------------------------------
//  Assemblage
// ------------------------------------------------------------
module assembly() {
    // plateau (z = 0 sur sa face supérieure)
    color("#4a90d9") translate([0, 0, -plate_t]) base_plate();

    // colonne
    color("#5aa469") bearing_tower();

    if (show_ghost) {
        ghost_nema17();
        translate([0, 0, 52]) ghost_coupler();
        translate([0, 0, bearing_lo_z]) ghost_bearing();
        translate([0, 0, bearing_hi_z]) ghost_bearing();
        translate([0, 0, 65]) ghost_shaft();
        ghost_lidar();
    }

    // berceau
    color("#e8a33d") translate([0, 0, hub_z0]) lidar_cradle();

    // plan de balayage (disque vertical dans le plan x = 0)
    if (show_plane)
        color([1, 0.25, 0.25, 0.18])
            translate([0, 0, optical_z]) rotate([0, 90, 0])
                cylinder(d = 260, h = 0.6, center = true);
}

assembly();

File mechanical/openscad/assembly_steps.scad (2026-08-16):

// ============================================================
//  Vues d'assemblage par étape (docs/assembly.md)
//
//  Usage :
//    openscad -D step=3 -o /tmp/step.stl assembly_steps.scad
//
//  step = 1 … 11  →  montage mécanique / câblage
// ============================================================

include <lib.scad>

use <base_plate.scad>
use <bearing_tower.scad>
use <lidar_cradle.scad>
use <electronics_box.scad>

step = 1;   // surchargé en ligne de commande : -D step=N

module ghost_nema17() {
    color("#404448") {
        translate([-nema_body / 2, -nema_body / 2, 0]) cube([nema_body, nema_body, nema_len]);
        translate([0, 0, nema_len]) cylinder(d = nema_boss_d, h = nema_boss_h);
        translate([0, 0, nema_len + nema_boss_h]) cylinder(d = nema_shaft_d, h = nema_shaft_l);
    }
}

module ghost_bearing() {
    color("#9aa0a6")
        difference() {
            cylinder(d = bearing_od, h = bearing_w);
            translate([0, 0, -0.5]) cylinder(d = bearing_id, h = bearing_w + 1);
        }
}

module ghost_coupler() {
    color("#c0392b") cylinder(d = coupler_d, h = coupler_l);
}

module ghost_shaft() {
    color("#d8dce0") cylinder(d = shaft_d, h = shaft_len);
}

// Ghost des trous de fixation (validation cotes datasheet § 5.1)
module ghost_lidar_holes() {
    color("#e74c3c", 0.35)
        for (y = [-1, 1])
            translate([plate_x, y * lidar_hole_y, optical_z - lidar_h / 2 + lidar_side_hole_z])
                rotate([0, 90, 0]) cylinder(d = lidar_screw_d, h = 8, center = true);
    color("#e74c3c", 0.35)
        translate([plate_x, 0, optical_z - lidar_h / 2 + lidar_top_hole_z])
            rotate([0, 90, 0]) cylinder(d = lidar_screw_d, h = 8, center = true);
    color("#f39c12", 0.25)
        translate([plate_x - 6, -lidar_cable_w / 2, optical_z - lidar_h / 2 - 14])
            cube([12, lidar_cable_w, lidar_cable_h + 14]);
}

module ghost_lidar() {
    color("#2b2f33")
        translate([plate_x, -lidar_w / 2, optical_z - lidar_h / 2])
            cube([lidar_thk, lidar_w, lidar_h]);
    color("#1a1d20")
        translate([-1.5, 0, optical_z]) rotate([0, 90, 0]) cylinder(d = 30, h = 3);
}

// Câble LiDAR simplifié (hélice le long de la colonne)
module ghost_lidar_cable() {
    color("#f39c12")
        for (i = [0:24])
            translate([14 * cos(i * 30), 14 * sin(i * 30), 40 + i * 5.5])
                rotate([0, 90, i * 30]) cylinder(d = 4, h = 6, center = true);
}

// Étape 1 — tige recoupée 115 mm
module step01() {
    rotate([0, 90, 0]) translate([0, 0, -shaft_len / 2]) ghost_shaft();
}

// Étape 2 — insert trépied (plateau à l'envers, bossage visible)
module step02() {
    rotate([180, 0, 0])
        translate([0, 0, -plate_t])
            color("#4a90d9") base_plate();
}

// Étape 3 — moteur vissé sous le plateau
module step03() {
    rotate([180, 0, 0]) {
        translate([0, 0, -plate_t]) color("#4a90d9") base_plate();
        translate([0, 0, -plate_t - nema_len]) ghost_nema17();
    }
}

// Étape 4 — roulements dans la colonne (seule)
module step04() {
    color("#5aa469") bearing_tower();
    translate([0, 0, bearing_lo_z]) ghost_bearing();
    translate([0, 0, bearing_hi_z]) ghost_bearing();
}

// Étape 5 — accouplement sur l'arbre moteur (plateau + moteur + coupleur)
module step05() {
    translate([0, 0, -plate_t]) color("#4a90d9") base_plate();
    ghost_nema17();
    translate([0, 0, 52]) ghost_coupler();
}

// Étape 6 — colonne fixée sur le plateau
module step06() {
    translate([0, 0, -plate_t]) color("#4a90d9") base_plate();
    color("#5aa469") bearing_tower();
    ghost_nema17();
}

// Étape 7 — tige + serrage accouplement
module step07() {
    translate([0, 0, -plate_t]) color("#4a90d9") base_plate();
    color("#5aa469") bearing_tower();
    ghost_nema17();
    translate([0, 0, 52]) ghost_coupler();
    translate([0, 0, 65]) ghost_shaft();
    translate([0, 0, bearing_lo_z]) ghost_bearing();
    translate([0, 0, bearing_hi_z]) ghost_bearing();
}

// Étape 8 — LD19 sur le berceau
module step08() {
    translate([0, 0, hub_z0]) {
        color("#e8a33d") lidar_cradle();
        ghost_lidar();
        ghost_lidar_holes();
    }
}

// Étape 9 — berceau sur la tige (tête tournante)
module step09() {
    translate([0, 0, -plate_t]) color("#4a90d9") base_plate();
    color("#5aa469") bearing_tower();
    translate([0, 0, 65]) ghost_shaft();
    translate([0, 0, bearing_lo_z]) ghost_bearing();
    translate([0, 0, bearing_hi_z]) ghost_bearing();
    translate([0, 0, hub_z0]) {
        color("#e8a33d") lidar_cradle();
        ghost_lidar();
    }
}

// Étape 10 — boîtier électronique
module step10() {
    color("#9b6bc4") electronics_box();
}

// Étape 11 — câble LiDAR + assemblage complet
module step11() {
    translate([0, 0, -plate_t]) color("#4a90d9") base_plate();
    color("#5aa469") bearing_tower();
    translate([0, 0, 65]) ghost_shaft();
    translate([0, 0, bearing_lo_z]) ghost_bearing();
    translate([0, 0, bearing_hi_z]) ghost_bearing();
    translate([0, 0, hub_z0]) {
        color("#e8a33d") lidar_cradle();
        ghost_lidar();
    }
    ghost_lidar_cable();
    translate([0, 0, -plate_t - box_iz / 2 - 8])
        rotate([0, 0, 45])
            color("#9b6bc4") electronics_box();
}

module dispatch() {
    if (step == 1) step01();
    else if (step == 2) step02();
    else if (step == 3) step03();
    else if (step == 4) step04();
    else if (step == 5) step05();
    else if (step == 6) step06();
    else if (step == 7) step07();
    else if (step == 8) step08();
    else if (step == 9) step09();
    else if (step == 10) step10();
    else if (step == 11) step11();
    else union();  // step inconnu → STL vide (erreur visible)
}

dispatch();

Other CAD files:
mechanical/openscad/base_plate.scad
mechanical/openscad/bearing_tower.scad
mechanical/openscad/electronics_box.scad
mechanical/openscad/electronics_lid.scad
mechanical/openscad/lib.scad
mechanical/openscad/lidar_cradle.scad
mechanical/openscad/test_fits.scad
mechanical/openscad/test_lidar_fit.scad

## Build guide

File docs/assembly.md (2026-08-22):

# Guide de montage

Durée : environ 3 h, hors impression. Suivre l'ordre indiqué — plusieurs
opérations deviennent impossibles une fois l'étape suivante réalisée.

Prérequis : [`printing.md`](printing.md) terminé, ajustements calibrés,
nomenclature [`bom.md`](bom.md) complète.

Illustrations dans [`assembly/`](assembly/) — régénérables via
[`generate_assembly_images.py`](generate_assembly_images.py).

> Les pièces **imprimées** sont en couleur (bleu, vert, orange, violet) ; les
> volumes **gris, rouge ou ambre** représentent les composants achetés (moteur,
> roulements, tige, accouplement, LiDAR, câble).

Pour l’ordre global du projet (logiciel, câblage, premier scan), voir
[`build.md`](build.md).

---

## Étape 1 — Préparation de la tige

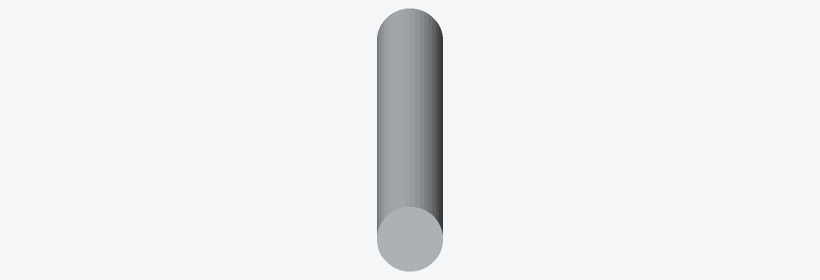
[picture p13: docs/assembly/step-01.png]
Étape 1 — tige Ø8 recoupée à 115 mm


1. Recouper la tige Ø8 à **115 mm exactement**.
2. Ébavurer et chanfreiner légèrement les deux extrémités à la lime.
3. Vérifier la rectitude en la roulant sur une surface plane.
4. Dégraisser à l'alcool.

> **115 mm, pas plus.** Une tige trop longue pénètre dans le corps du STL-19P et
> l'empêche de se plaquer sur le berceau.

## Étape 2 — Insert de trépied

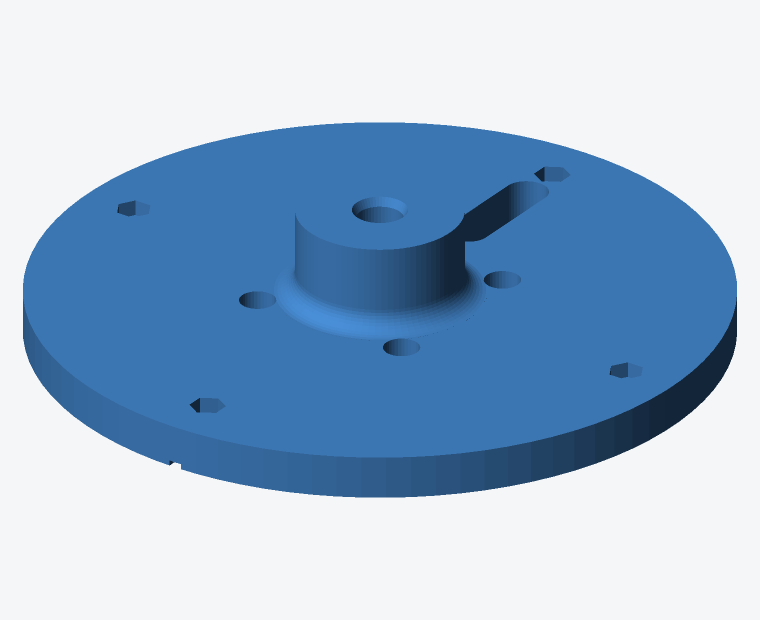
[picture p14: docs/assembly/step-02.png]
Étape 2 — bossage insert 1/4"-20


Voir [`printing.md`](printing.md) § « Pose de l'insert ». À faire maintenant :
le bossage est encore accessible de partout.

Contrôle : visser une vis 1/4"-20 à la main, elle doit entrer d'équerre et sans
point dur.

## Étape 3 — Moteur sur le plateau

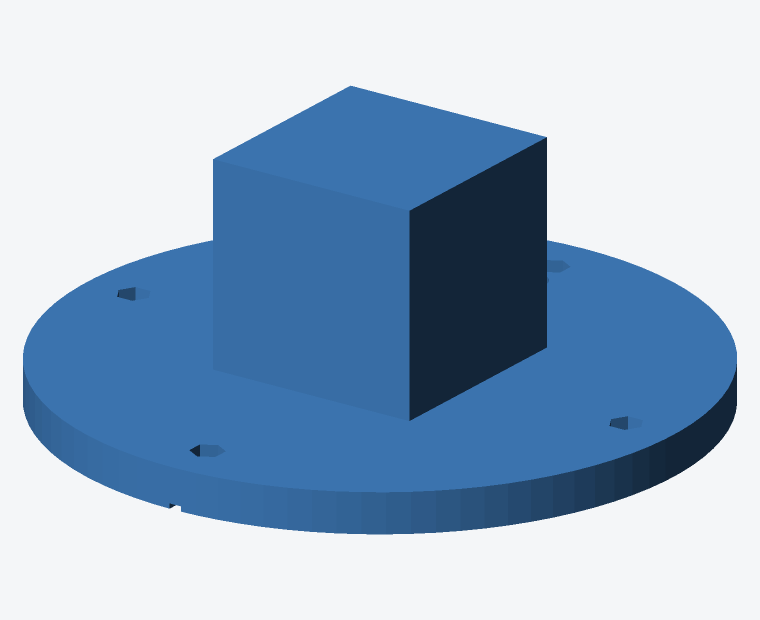
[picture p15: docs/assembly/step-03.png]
Étape 3 — NEMA 17 vissé sous le plateau


1. Poser le plateau **à l'envers** sur l'établi.
2. Présenter le NEMA 17, arbre vers le haut, bossage de centrage engagé dans
   son dégagement.
3. Orienter la sortie de câble vers le repère gravé (azimut 0°, côté
   passe-câble).
4. Visser **par le dessous** : vis à travers le plateau et la bride du moteur,
   **écrou M3** côté moteur (les 17HS4401 courants ont des **trous traversants**,
   pas de taraudage — les vis fournies avec le moteur conviennent).
5. Serrer en croix, sans forcer.

Contrôle : l'arbre doit tourner librement, sans point dur, et le moteur ne doit
pas basculer.

## Étape 4 — Roulements dans la colonne

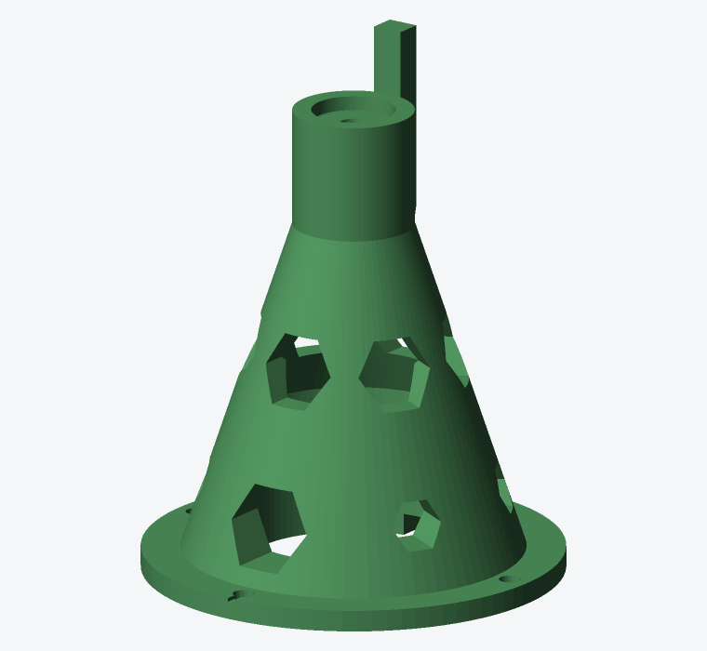
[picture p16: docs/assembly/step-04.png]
Étape 4 — deux 608ZZ dans la colonne


Les deux roulements s'insèrent **par le haut**.

1. Poser la colonne verticalement, bride en bas.
2. Engager le premier 608ZZ dans le col. Il traverse librement le dégagement
   Ø23,5 puis rencontre son logement à z 82.
3. Le pousser **d'équerre** jusqu'à ce qu'il porte sur l'épaulement. Utiliser
   un tube ou une douille de Ø ≈ 21 mm ; ne jamais appuyer sur la bague
   intérieure.
4. Insérer le second 608ZZ, qui s'arrête dans son logement à z 122.

Contrôle : les deux roulements doivent être bien perpendiculaires à l'axe. Une
tige Ø8 passée à travers les deux doit coulisser librement, sans point dur —
c'est le test décisif de la coaxialité.

> Si la tige coince, les roulements ne sont pas d'équerre. Les ressortir et
> recommencer : ce défaut se traduirait par un point dur à chaque tour et par
> des pas perdus.

## Étape 5 — Accouplement

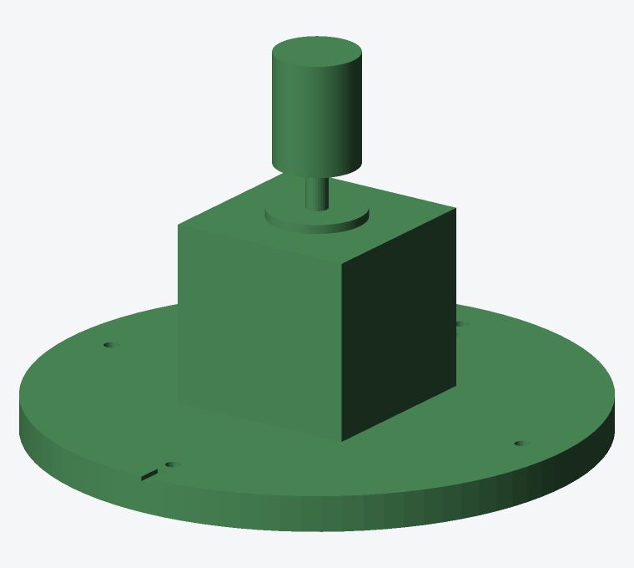
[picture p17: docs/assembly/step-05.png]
Étape 5 — accouplement sur l'arbre moteur


1. Glisser l'accouplement sur l'arbre du moteur, engagé sur **12 mm**.
2. Ne pas encore serrer les vis.
3. Positionner le haut de l'accouplement à z 77.

## Étape 6 — Colonne sur le plateau

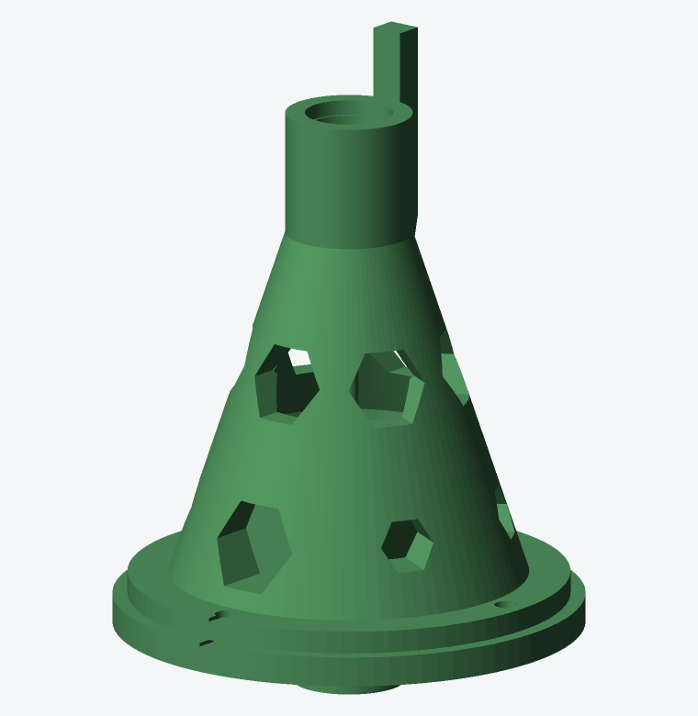
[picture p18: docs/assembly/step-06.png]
Étape 6 — colonne fixée sur le plateau


1. Faire descendre la colonne sur le moteur, en la présentant bien droite.
2. Faire passer le câble moteur par l'encoche de bride et la lumière du
   plateau.
3. Aligner les 4 trous de fixation.
4. Visser les M3×20 par le haut, écrous dans les empreintes sous le plateau.
5. Serrer en croix, progressivement.

Contrôle : la bride doit reposer à plat, sans jeu de basculement.

## Étape 7 — Tige et accouplement

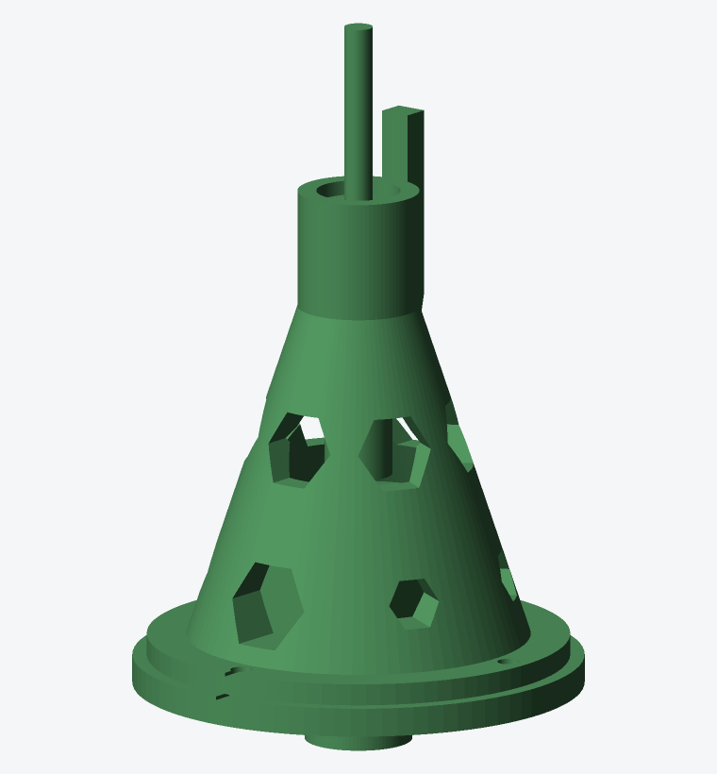
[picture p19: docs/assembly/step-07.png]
Étape 7 — tige traversant les roulements


1. Introduire la tige par le haut, à travers les deux roulements.
2. La descendre jusqu'à l'engager de 12 mm dans l'accouplement (elle affleure
   alors z 65 en bas, z 180 en haut).
3. Par les **trois fenêtres hexagonales** de la colonne, serrer les vis de
   l'accouplement côté moteur puis côté tige.
4. Vérifier au pied à coulisse que la tige dépasse bien de 47 mm au-dessus du
   sommet de la colonne.

Contrôle : faire tourner la tige à la main. Elle doit tourner régulièrement,
sans point dur ni jeu radial perceptible. Le moteur non alimenté oppose une
résistance de détente : c'est normal.

> C'est la dernière occasion d'accéder à l'accouplement.

## Étape 8 — STL-19P sur le berceau

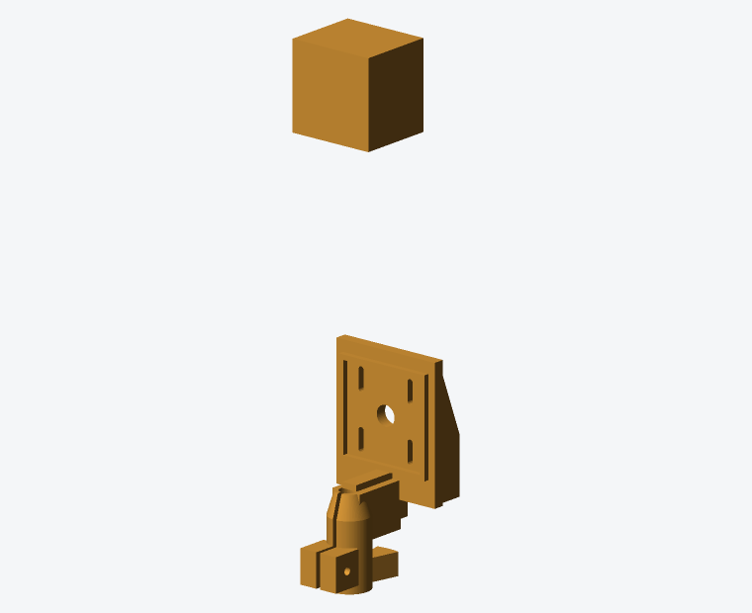
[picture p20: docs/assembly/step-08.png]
Étape 8 — STL-19P dans le berceau


1. **Relever au pied à coulisse la hauteur du plan optique** du STL-19P par
   rapport à sa face de fixation. Valeur supposée : 22 mm. Voir
   [`calibration.md`](calibration.md) § 1.
2. Si l'écart dépasse 2 mm, corriger `lidar_optical_offset` dans `params.scad`
   et réimprimer le berceau. Sinon, rattraper par les lumières oblongues.
3. Poser le STL-19P dans le rebord de centrage, **câble / nappe vers le bas**
   (fente **16 mm** ouverte en bas, à travers la platine).
4. Visser les **3 M2,5** dans les oreilles (latérales + haute, loin du câble).
5. Centrer le plan optique sur la hauteur cible, puis serrer.
6. Passer le câble par le trou central de la platine.

## Étape 9 — Berceau sur la tige

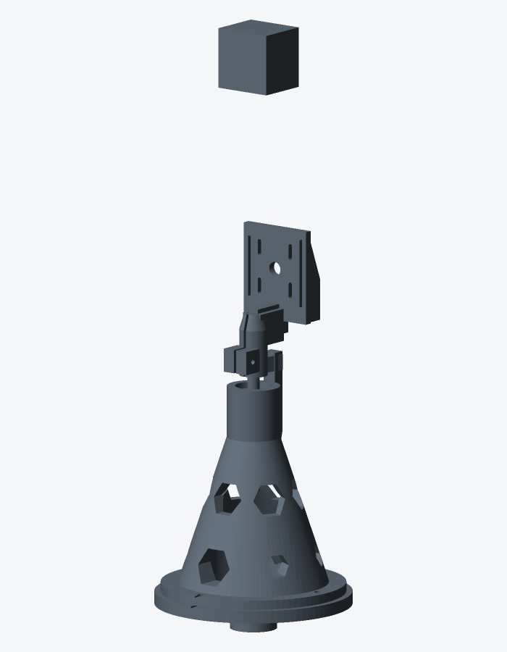
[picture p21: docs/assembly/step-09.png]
Étape 9 — tête tournante sur la tige


1. Enfiler le moyeu du berceau sur la tige, jusqu'à ce qu'il porte sur la bague
   intérieure du roulement supérieur.
2. Orienter le secteur de butée en regard du contrefort de la colonne.
3. Serrer la vis M3×25 du collier, progressivement.

Contrôle : la tête complète doit tourner d'un bloc, sans jeu entre le berceau
et la tige. En butée, le secteur doit rencontrer franchement le contrefort.

## Étape 10 — Électronique

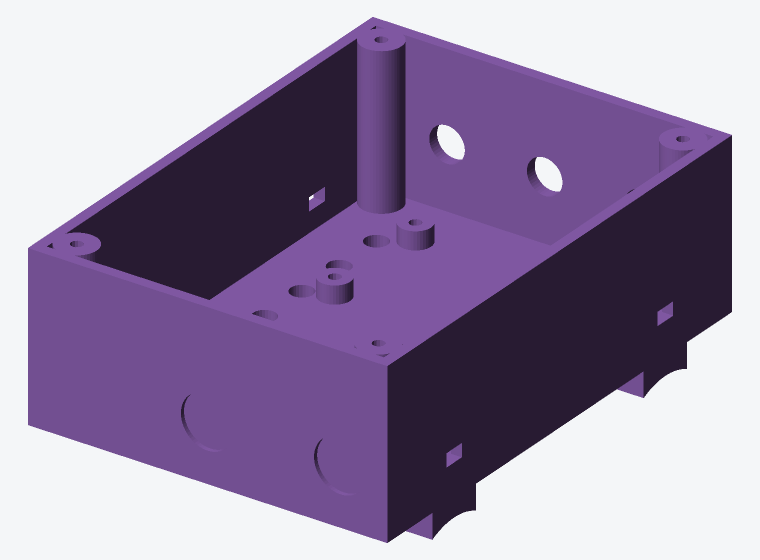
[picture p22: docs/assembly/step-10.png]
Étape 10 — boîtier électronique


Câbler **hors tension**, en suivant [`wiring.md`](wiring.md).

1. Disposer les modules dans le boîtier : ESP32-S3 côté USB, TMC2209 avec son
   dissipateur, buck et trigger PD à l'opposé.
2. Fixer par vis autotaraudeuses dans les bossages, ou par rilsan.
3. Coller le MPU6050 **à plat au fond**, face parallèle au plateau.
4. Souder la résistance de 1 kΩ sur la ligne TX vers **PDN** (pas USART).
   Ne pas câbler DIAG : le homing passe par l'UART.
5. Mesurer les tensions du trigger PD (12 V) et du buck (5 V) **avant** de les
   relier aux consommateurs.
6. Fermer le couvercle, 4 vis M3×8.
7. Sangler le boîtier sur la colonne centrale du trépied par rilsan.

## Étape 11 — Câble du LiDAR

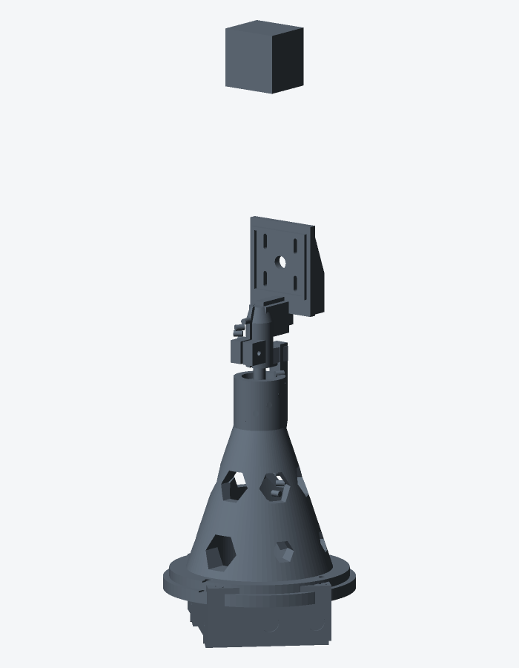
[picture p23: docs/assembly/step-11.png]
Étape 11 — câble LiDAR en hélice lâche


1. Descendre le câble le long de la colonne, en hélice lâche.
2. Laisser **120 mm de mou**.
3. Fixer par rilsan sur le berceau et en bas de la colonne, jamais en tension.
4. Faire tourner la tête à la main sur ±90° : le câble doit suivre librement,
   sans jamais tirer ni frotter sur une arête.

## Étape 12 — Premières mises sous tension

Étape 12 — séquence de mise sous tension

Dans cet ordre, sans jamais brûler d'étape.

**12a — Sans le moteur.** Alimenter, vérifier au moniteur série que le STL-19P
émet des trames valides et que le portail Wi-Fi apparaît. Configurer le réseau.

**12b — Moteur à faible courant.** Régler 300 mA, faire tourner de 10° dans les
deux sens. Écouter : le balayage doit être quasi silencieux en StealthChop.

**12c — Prise de référence.** Lancer le homing StallGuard. Ajuster `SGTHRS`
jusqu'à une détection franche et répétable sur dix essais.

**12d — Scan complet.** Passer à 700 mA et lancer un balayage de 180°.

## Contrôle final

- [ ] La tête tourne librement sur 180°, sans point dur
- [ ] Aucun câble en tension ni frottant
- [ ] Le plan de balayage du STL-19P contient bien l'axe de rotation
- [ ] Le homing est répétable à mieux que 0,5° sur dix essais
- [ ] Le trépied est stable, le scanner ne bascule pas en rotation
- [ ] Aucun échauffement anormal après 5 min de fonctionnement

Passer ensuite à [`calibration.md`](calibration.md).

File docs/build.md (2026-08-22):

# Guide de construction pas à pas

Parcours complet, de la commande des pièces au premier nuage de points.
Chaque étape renvoie aux fiches détaillées ; ce document fixe **l’ordre** et
les contrôles de passage.

Durée indicative (hors délais de livraison) :

| Phase | Temps |
|---|---|
| Commandes + impression | 1–2 jours (dont ~9 h d’impression) |
| Montage mécanique | ~3 h |
| Câblage + firmware | ~2–3 h |
| Premier scan + calibration | ~2 h |
| **Total atelier** | **environ 1 week-end** |

Vue d'assemblage

---

## Vue d’ensemble

```
 0. Lire le principe
 1. Vérifier / compléter le BOM
 2. Préparer le PC hôte (sans matériel)
 3. Imprimer (coupon → pièces)
 4. Monter la mécanique
 5. Câbler et alimenter
 6. Flasher le firmware
 7. Configurer Wi‑Fi + panneau web
 8. Premier scan d’essai
 9. Calibrer
10. Scans réels + post-traitement
```

Ne pas sauter l’ordre : plusieurs opérations (insert trépied, Vref TMC, flash
USB initial) deviennent pénibles une fois le boîtier fermé ou la tête montée.

---

## Étape 0 — Comprendre le principe (30 min)

Lire, dans cet ordre :

1. [README.md](../README.md) — vue d’ensemble  
2. [geometry.md](geometry.md) — pourquoi le LiDAR est sur la tranche (STL-19P),
   et pourquoi
   θ = élévation / ψ = azimut  
3. [architecture.md](architecture.md) — qui fait quoi (ESP32 vs PC)

**Contrôle.** Tu dois pouvoir expliquer en une phrase : *le LiDAR balaie un
plan vertical ; le moteur tourne ce plan de 180° ; l’ESP32 envoie du polaire ;
le PC fait le XYZ.*

---

## Étape 1 — Matériel (commande)

### 1.1 Inventaire

Ouvrir [bom.md](bom.md) et cocher, section par section :

**A — Déjà commandé**

- [ ] A1 STL-19P (FHL-LD19P)
- [ ] A2 ESP32-S3 DevKitC-1 **N16R8**
- [ ] A3 Driver TMC2209
- [ ] A4 Moteur NEMA 17 **pas à pas 4 fils** (pas de BLDC brushless)
- [ ] A5 MPU6050
- [ ] A6 Roulements 608ZZ (×2 min.)
- [ ] A7 Insert laiton 1/4"-20 UNC **× 10 × 8 mm**
- [ ] A8 Trigger USB-C PD
- [ ] A9 Buck 12 V → 5 V 3 A
- [ ] A10 Power bank USB-C PD

**B — À acquérir**

- [ ] B1 Tige Ø8 (≥ 120 mm, à recouper à 115 mm)
- [ ] B2 Accouplement flexible 5 → 8 mm
- [ ] B3–B7 Visserie M3 / M2,5 (voir [bom.md](bom.md))
- [ ] B8 Colliers rilsan
- [ ] B9 Fil silicone AWG24–26
- [ ] B10 Niveau à bulle (optionnel)

**C — Pièces imprimées** (réalisées à l’[étape 3](#étape-3--impression-3d), pas à acheter)

- [ ] C0 `test_fits` (coupon — en premier)
- [ ] C1 `base_plate`
- [ ] C2 `bearing_tower`
- [ ] C3 `lidar_cradle`
- [ ] C4 `electronics_box`
- [ ] C5 `electronics_lid`

**D — Outillage**

- [ ] Imprimante 3D (volume ≥ 130 × 130 × 140 mm)
- [ ] Fer à souder (pose insert)
- [ ] Pied à coulisse
- [ ] Multimètre
- [ ] Clés Allen 1,5 / 2 / 2,5 mm
- [ ] Scie à métaux ou Dremel (recoupe tige)

**E — Vigilance achat** : relire [bom.md](bom.md) § E (variante STL-19P, moteur
pas à pas, N16R8, accouplement flexible).

### 1.2 Points critiques à l’achat

| Pièce | Vigilance |
|---|---|
| ESP32-S3 | Variante **N16R8** (16 Mo flash / 8 Mo PSRAM) |
| Moteur | **Pas à pas 4 fils** NEMA 17 (STEP/DIR) — pas de BLDC 42BL3802 |
| Accouplement | **Flexible** 5→8 mm, pas rigide |
| Tige | Acier rectifié Ø8, à recouper à **115 mm** |
| LiDAR | **STL-19P** : 3 oreilles M2,5, 5 000 Hz, détection verre |

**Contrôle.** Toute la section **B** est chez toi avant le montage final.
La section **C** se coche au fur et à mesure des impressions. On peut
imprimer en attendant la fin des livraisons A/B.

---

## Étape 2 — Station hôte sur le PC (sans scanner)

À faire **pendant** que les colis et les impressions arrivent.

```bash
cd host
python -m venv .venv
source .venv/bin/activate          # Windows : .venv\Scripts\activate
pip install -e ".[dev]"
pytest -q                          # 38 tests attendus
```

Sous WSL2, pour Open3D :

```bash
export DISPLAY=:0                  # WSLg
```

Valider le pipeline avec le simulateur (deux terminaux) :

```bash
# A
lidar-visualize --port 9000

# B
lidar-simulate --host 127.0.0.1 --port 9000 --fast
```

Sans fenêtre : `lidar-receive --port 9000 --output scans/sim.pcd --auto-stop`.

Détails : [open3d.md](open3d.md), [host/README.md](../host/README.md).

**Contrôle.** Tu vois une pièce synthétique aux murs plans, ou un `.pcd` non
vide. Si ce n’est pas le cas, corriger l’hôte **avant** de toucher au matériel.

---

## Étape 3 — Impression 3D

Fiche détaillée : [printing.md](printing.md). STL : `mechanical/stl/`.

### 3.1 Coupon de calibration (obligatoire en premier)

1. Imprimer `test_fits.stl` (PETG, 0,2 mm, 3 périmètres, 20 %).  
2. Tester les logements de roulement et les trous d’insert.  
3. Reporter les jeux dans `mechanical/openscad/params.scad` si besoin.  
4. Régénérer : `cd mechanical/openscad && make`.

**Contrôle.** Un 608ZZ s’enfonce ferme d’équerre ; l’insert 1/4"-20 se pose
sans fendre le bossage.

### 3.2 Pièces structurelles

Ordre recommandé :

| # | Fichier | Remarques |
|---|---|---|
| 1 | `base_plate` | Imprimée **retournée** |
| 2 | `bearing_tower` | 5 périmètres, 40 % — pièce critique |
| 3 | `lidar_cradle` | Imprimée **couchée** |
| 4 | `electronics_box` + `electronics_lid` | |

Environ 9 h / 220 g PETG au total.

**Contrôle.** Toutes les pièces ébavurées ; colonnette et lamages propres ;
aucun stringing dans les logements de roulement.

---

## Étape 4 — Montage mécanique

Fiche détaillée : [assembly.md](assembly.md). Conception : [mechanical.md](mechanical.md).

Suivre **strictement** l’ordre du guide de montage. Résumé :

| # | Action | Contrôle |
|---|---|---|
| 1 | Recouper la tige à **115 mm**, ébavurer | Longueur exacte |
| 2 | Pose à chaud de l’insert 1/4"-20 dans le plateau | Vis trépied d’équerre |
| 3 | NEMA 17 sous le plateau (4× M3 + écrou M3) | Arbre libre, moteur stable |
| 4 | Deux 608ZZ dans la colonne (par le haut) | Portage sur épaulements |
| 5 | Colonne sur plateau (4× M3×20) | Bride à plat, pas de jeu |
| 6 | Accouplement flexible 5→8 | Vis serrées, pas de contrainte |
| 7 | Tige dans les roulements + accouplement | Tourne libre, sans frottement |
| 8 | Berceau + STL-19P sur la tige | Plan optique vertical, 3× M2,5, serrage M3 |
| 9 | Boîtier électronique (sans fermer le couvercle) | Sanglage trépied plus tard |

**Contrôle final mécanique.**

- [ ] La tête tourne à la main sur ~180° jusqu’à la butée  
- [ ] Aucun frottement câble / colonne  
- [ ] Le STL-19P ne touche pas la colonne ni le plateau  
- [ ] Le trépied reçoit bien le plateau (test à blanc)

---

## Étape 5 — Câblage et alimentation

Fiche et **plans SVG** : [wiring.md](wiring.md)
([ensemble](wiring/01_ensemble.svg),
[alimentation](wiring/02_alimentation.svg),
[signaux](wiring/03_signaux.svg),
[brochage](wiring/04_brochage.svg)).

### 5.1 Alimentation (hors ESP32 d’abord)

1. Power bank → trigger USB-C PD réglé sur **12 V**.  
2. 12 V → entrée TMC2209 (VM) **et** entrée du buck.  
3. Buck réglé / vérifié à **5,0 V** à vide.  
4. Mesurer au multimètre **avant** de brancher ESP32 / LD19.

**Contrôle.** 12 V ±5 % sur le rail moteur ; 5,0 V ±0,1 V sur le rail logique.

### 5.2 Signaux

Suivre le tableau de [wiring.md](wiring.md) (GPIO S3) :

| Fonction | Broches typiques |
|---|---|
| LD19 UART RX + PWM | GPIO 18, 17 |
| TMC STEP / DIR / EN | GPIO 4, 5, 6 |
| TMC UART | GPIO 7, 15 → **PDN** (pas USART) ; pas de DIAG |
| MPU6050 I2C | GPIO 8, 9 |
| Wi‑Fi reset | BOOT (GPIO 0) |

Rappels :

- MPU6050 en **3,3 V**, pas 5 V  
- Résistance 1 kΩ sur la ligne UART TMC si le module le demande  
- Ne **jamais** utiliser GPIO 33–37 sur le N16R8 (PSRAM)

### 5.3 Courant TMC2209 (Vref)

Régler le potentiomètre selon [wiring.md](wiring.md) pour viser ~700 mA RMS
en scan (formule / table du doc). StealthChop via UART sera peaufiné au flash.

**Contrôle.** Multimètre sur Vref ; driver froid à l’arrêt ; pas d’odeur de
brûlé au premier essai moteur.

---

## Étape 6 — Firmware

Fiche : [firmware/README.md](../firmware/README.md).

### 6.1 Premier flash **obligatoirement en USB** — amorce OTA

On flashe d'abord l'amorce : Wi-Fi + OTA firmware + OTA LittleFS, rien
d'autre. Une fois le réseau configuré, le câble USB n'est plus nécessaire.

```bash
cd firmware
pio run -e seed -t upload
pio device monitor
```

Attendu sur le moniteur :

```
[lidar-scanner] amorce OTA 0.1.0-seed
[wifi] …
[seed] http://lidar-scanner.local/ …
```

Configurer le Wi-Fi via `LiDAR-Scanner-Setup`, puis ouvrir
`http://lidar-scanner.local/`. Les mises à jour suivantes : [ota.md](ota.md)
(`pio run -e ota -t upload` / `-t uploadfs`, ou la page web).

**Contrôle.** Flash OK, pas de reboot en boucle, page d'amorce joignable
en HTTP, OTA firmware et filesystem acceptés.

### 6.2 Firmware scanner (OTA)

Une fois le Wi‑Fi configuré via le portail, téléverser le firmware complet
(scanner + panneau de commande) :

```bash
cd firmware
pio run -e ota -t upload
# si mDNS échoue :
pio run -e ota -t upload --upload-port 192.168.x.x
```

Attendu sur le moniteur (USB optionnel) ou dans `/api/status` :

```
[lidar-scanner] firmware 0.4.x
```

**Contrôle.** Page web avec sections Commande, Matériel, Diagnostics, Réglages
et OTA ; `/api/status` répond en JSON.

---

## Étape 7 — Wi‑Fi et panneau web

Fiches : [wifi.md](wifi.md), [web.md](web.md).

1. Au premier boot (ou après BOOT maintenu) : se connecter à l’AP
   `LiDAR-Scanner-Setup`.  
2. Renseigner SSID, mot de passe, **IP du PC hôte**, mot de passe OTA.  
3. L’ESP redémarre sur le Wi‑Fi local.  
4. Ouvrir `http://lidar-scanner.local/` (ou l’IP affichée au moniteur).  
5. S’authentifier : `admin` / mot de passe OTA.

Sur le panneau, sans lancer de long scan :

- [ ] **Matériel** : Wi‑Fi OK ; LiDAR / entraînement / IMU cohérents avec le câblage réel
- [ ] Diagnostics : état `idle`, heap raisonnable, RSSI visible
- [ ] Réglages : valeurs par défaut présentes
- [ ] Bouton **Rehomer** : pastille Entraînement → OK (ajuster StallGuard si échec)
- [ ] **Arrêt d'urgence** : moteur coupé, Entraînement → Ko (EN relâché)
- [ ] **Redémarrer** : l'ESP revient en ~10 s, page joignable

**Contrôle.** Homing fiable ; page web stable ; l’IP hôte dans le portail est
bien celle du PC qui écoutera le port UDP 9000.

---

## Étape 8 — Premier scan d’essai

Fiches : [operation.md](operation.md), [open3d.md](open3d.md).

### 8.1 Préparer la scène

- Pièce peu meublée, **volets fermés**, miroirs couverts  
- Scanner sur trépied, à ~1,5 m, de niveau (bulle)  
- Power bank pleine, boîtier sanglé sur la colonne du trépied  

### 8.2 PC hôte

```bash
cd host && source .venv/bin/activate
lidar-visualize --port 9000
# ou enregistrement :
# lidar-receive --port 9000 --output scans/essai1.pcd --auto-stop
```

### 8.3 Lancer le balayage

Sur le panneau web : **Lancer le scan**.

Surveiller :

| Symptôme | Action |
|---|---|
| Nuage vide | IP hôte / même LAN / pare-feu UDP 9000 |
| Murs courbes | Normal tant que non calibré — noter pour l’étape 9 |
| Homing raté | Monter / baisser seuil StallGuard sur le panneau |
| Vibrations | Courant trop haut / StealthChop / sol instable |
| CRC mauvais | Câble UART LD19, masse, 5 V |

**Contrôle.** Au moins quelques dizaines de milliers de points ; un `.pcd`
enregistré ; fin de scan signalée (`--auto-stop` ou fenêtre fermée proprement).

---

## Étape 9 — Calibration

Fiche : [calibration.md](calibration.md). Fichier :
`host/calibration.json`.

Mesures à faire **une fois** (puis itérer) :

1. Bras de levier (pied à coulisse) → `lever_arm_mm`  
2. Offset azimut ψ  
3. Offset élévation θ  
4. Nivellement (`g_zero`) — relever `imu_gx/gy/gz` sur le panneau web avec le
   plateau de niveau à la bulle, reporter dans `calibration.json` (voir
   [calibration.md](calibration.md) § 4)
5. Filtres `rho_min` / intensité  

Rescanner une position de contrôle après chaque correction majeure.

**Contrôle.** Murs plans, angles droits, sol horizontal dans Open3D.

---

## Étape 10 — Usage courant

1. Préparer les lieux ([operation.md](operation.md))  
2. `lidar-receive` ou `lidar-visualize`  
3. Lancer le scan depuis le web  
4. Repositionner (30 % de recouvrement) pour les angles morts / nadir  
5. Fusionner :  
   `lidar-register scans/salon_*.pcd --output salon.pcd`  
6. Mailler :  
   `lidar-mesh salon.pcd --output salon.ply --depth 8`  

OTA pour les évolutions firmware : [ota.md](ota.md).  
Réglages fins (StallGuard, courants, vitesse) : [web.md](web.md).

---

## Checklist « prototype terminé »

- [ ] BOM A+B complet  
- [ ] Coupon `test_fits` validé, pièces imprimées  
- [ ] Mécanique montée, rotation libre jusqu’à butée  
- [ ] 12 V / 5 V mesurés, Vref TMC réglé  
- [ ] Firmware scanner **0.4.x** flashé (OTA ou USB)
- [ ] Section **Matériel** du web : tous les composants câblés en **OK**
- [ ] Homing StallGuard fiable  
- [ ] Au moins un `.pcd` réel enregistré  
- [ ] `calibration.json` renseigné (même approximatif)  
- [ ] Un second scan + `lidar-register` réussis  

---

## En cas de blocage

| Étape | Doc dépannage |
|---|---|
| Impression / jeux | [printing.md](printing.md) |
| Montage | [assembly.md](assembly.md) |
| Alim / GPIO | [wiring.md](wiring.md) |
| Wi‑Fi | [wifi.md](wifi.md) |
| Web / OTA | [web.md](web.md), [ota.md](ota.md) |
| Nuage / Open3D | [open3d.md](open3d.md), [operation.md](operation.md) |
| Géométrie douteuse | [geometry.md](geometry.md), [calibration.md](calibration.md) |

---

## Index des documents

| Document | Rôle |
|---|---|
| **Ce guide** | Ordre de construction |
| [bom.md](bom.md) | Nomenclature |
| [printing.md](printing.md) | Impression |
| [mechanical.md](mechanical.md) | Conception mécanique |
| [assembly.md](assembly.md) | Montage détaillé |
| [wiring.md](wiring.md) | Électrique |
| [wifi.md](wifi.md) / [web.md](web.md) / [ota.md](ota.md) | Réseau & IHM |
| [calibration.md](calibration.md) | Mesures de calage |
| [operation.md](operation.md) | Conduite des scans |
| [open3d.md](open3d.md) | Visualisation & mesh |
| [geometry.md](geometry.md) | Maths |
| [architecture.md](architecture.md) | Logiciel |

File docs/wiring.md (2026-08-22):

# Câblage et pinout

Plans de câblage du scanner 3D LiDAR (ESP32-S3 N16R8).  
Figures vectorielles dans [`wiring/`](wiring/) :

- plans bloc — [`generate_wiring_svgs.py`](generate_wiring_svgs.py)
- **schémas électriques classiques** — [`generate_schematic_svgs.py`](generate_schematic_svgs.py)

## Schémas électriques (style circuit)

| Schéma | Fichier | Contenu |
|---|---|---|
| Alimentation | [wiring/05_schematic_alimentation.svg](wiring/05_schematic_alimentation.svg) | BAT1, trigger, buck, rails 12 V / 5 V / 3,3 V |
| Signaux | [wiring/06_schematic_signaux.svg](wiring/06_schematic_signaux.svg) | ESP32-S3, LD19, MPU6050, TMC2209, R1 1 kΩ |
| Ensemble | [wiring/07_schematic_ensemble.svg](wiring/07_schematic_ensemble.svg) | Vue d’ensemble compacte |

Alimentation — schéma classique

Signaux — schéma classique

Ensemble — schéma classique

## Plans bloc (aperçu)

| Plan | Fichier | Contenu |
|---|---|---|
| Ensemble | [wiring/01_ensemble.svg](wiring/01_ensemble.svg) | Tête / boîtier / énergie / hôte |
| Alimentation | [wiring/02_alimentation.svg](wiring/02_alimentation.svg) | 12 V, 5 V, 3,3 V, masse |
| Signaux | [wiring/03_signaux.svg](wiring/03_signaux.svg) | UART, I2C, STEP/DIR/EN |
| Brochage | [wiring/04_brochage.svg](wiring/04_brochage.svg) | Table GPIO fil par fil |

Ensemble

Alimentation

Signaux

Brochage

---

## 1. Architecture d'alimentation

```mermaid
flowchart LR
  PB["Power bank<br/>USB-C PD 100 W"] --> TR["Trigger PD<br/>12 V"]
  TR --> TMCV["TMC2209 VM"]
  TR --> BUCK["Buck<br/>12 V → 5 V 3 A"]
  BUCK --> LD["LD19 P5V 5 V"]
  BUCK --> ESP["ESP32-S3 5V/VIN"]
  ESP --> MPU["MPU6050 3,3 V"]
  ESP --> VIO["TMC2209 VIO 3,3 V"]
```

```
  Power bank USB-C PD 100 W
            │
            ▼
   Module trigger PD  ──► 12 V
            ├──────────────────────► TMC2209  VM
            │
            └──► Buck 12 V → 5 V 3 A
                       ├────────────► LD19        P5V (5 V, vert)
                       └────────────► ESP32-S3    5V / VIN
                                          │
                                          └──3,3 V──► MPU6050
                                                      TMC2209 VIO
```

**Masse commune obligatoire** entre trigger PD, buck, ESP32, TMC2209, moteur et
LiDAR. Une masse flottante sur le TMC2209 est la cause classique de pas perdus
et de comportements erratiques.

Consommation totale : environ 8 à 12 W en balayage.

---

## 2. Brochage de l'ESP32-S3 DevKitC-1 (N16R8)

| Fonction | GPIO | Sens | Fil conseillé | Remarques |
|---|---|---|---|---|
| LiDAR UART RX | 18 | Entrée | Blanc | TX du STL-19P |
| LiDAR PWM | 17 | Sortie | Noir | PWM du STL-19P |
| I2C SDA | 8 | E/S | Bleu | MPU6050 |
| I2C SCL | 9 | Sortie | Vert | MPU6050 |
| TMC STEP | 4 | Sortie | Orange | |
| TMC DIR | 5 | Sortie | Violet | |
| TMC EN | 6 | Sortie | Gris | Actif à l'état bas |
| TMC UART TX | 7 | Sortie | Brun | Via résistance **1 kΩ** → **PDN** (pas USART) |
| TMC UART RX | 15 | Entrée | Brun | Directement sur **PDN** |
| BOOT | 0 | Entrée | — | Reset Wi‑Fi si maintenu au démarrage |
| GND | — | — | Noir | Masse commune |
| 3V3 | — | Sortie | Rouge clair | MPU + TMC VIO |
| 5V / VIN | — | Entrée | Rouge | Depuis le buck |

### Broches à ne pas utiliser

Sur la variante **N16R8**, la PSRAM octale occupe les **GPIO 33 à 37** : les
utiliser fait planter la carte au démarrage. Éviter également les GPIO 26 à 32
(flash SPI) et 19/20 (USB natif).

```mermaid
flowchart TB
  subgraph ESP["ESP32-S3"]
    G18[GPIO18 RX]
    G17[GPIO17 PWM]
    G8[GPIO8 SDA]
    G9[GPIO9 SCL]
    G4[GPIO4 STEP]
    G5[GPIO5 DIR]
    G6[GPIO6 EN]
    G7[GPIO7 TX]
    G15[GPIO15 RX]
  end
  LD19["LD19"] --> G18
  G17 --> LD19
  G8 <--> MPU["MPU6050"]
  G9 --> MPU
  G4 --> TMC["TMC2209"]
  G5 --> TMC
  G6 --> TMC
  G7 -->|1 kΩ| TMC
  G15 --- TMC
  TMC --> MOT["NEMA 17"]
```

---

## 3. LiDAR STL-19P (protocole LD19)

Connecteur JST 4 points côté capteur. Brochage identique à la famille LD19.

| STL-19P (ZH1.5T) | Vers | Fil **de cet exemplaire** |
|---|---|---|
| **P5V** | Sortie buck 5 V | **Vert** |
| **GND** | Masse commune | **Jaune** |
| **TX** | GPIO 18 | **Blanc** |
| **PWM** | GPIO 17 | **Noir** |

Le **jaune est la masse**, pas le 5 V. Le **noir est le PWM**, pas la masse.

Le LD19 communique en **UART 230 400 bauds, 8N1**, niveaux 3,3 V, compatibles
directement avec l'ESP32-S3. La liaison est **unidirectionnelle** : le capteur
émet en continu, aucune commande à lui envoyer.

### Commande de vitesse par PWM

Broche PWM à la masse (ou non connectée) : régulation interne à 10 Hz.
Signal carré de 30 kHz appliqué : la vitesse devient réglable de 5 à 13 Hz par
le rapport cyclique, asservie en boucle fermée par le capteur.

Le firmware règle **5 Hz**, ce qui double la résolution angulaire (0,4° au lieu
de 0,8°) sans aucun coût. Voir [geometry.md](geometry.md) § 6.

### Câble tournant

Le câble du LD19 est le seul à traverser la liaison tournante. Sur ±90° de
débattement, une simple boucle de mou suffit : ni bague tournante, ni contact
glissant. Laisser environ 120 mm de mou en hélice lâche le long de la colonne
et fixer les deux extrémités par collier rilsan, jamais en tension.

---

## 4. MPU6050

**Monté sur la base fixe**, pas sur la tête tournante — il ne sert qu'à mesurer
la verticale au repos.

| MPU6050 | ESP32-S3 |
|---|---|
| VCC | 3,3 V |
| GND | GND |
| SDA | GPIO 8 |
| SCL | GPIO 9 |
| AD0 | GND (adresse 0x68) |

Ne **pas** l'alimenter en 5 V : la plupart des cartes GY-521 ont un régulateur,
mais les lignes I2C reviennent alors en 5 V sur l'ESP32.

Le coller à plat dans le boîtier électronique, faces bien parallèles au plateau
de base. Son orientation exacte n'a pas besoin d'être parfaite : la calibration
mesure l'écart une fois pour toutes.

---

## 5. TMC2209 TWOTREES V2.0 et NEMA 17

Module **TWOTREES TMC2209 V2.0** (16 broches, dissipateur au centre, **RP1**
en bas). Orientation : sérigraphie `TWOTREES` en haut, **EN** en bas à droite.

```
        GND    DIR
        VIO    STEP
        M2B    CLK      ← laisser en l'air
        M2A    USART    ← ne pas câbler (UART alternatif)
        M1A    PDN      ← UART (usine)
        M1B    MS2
        GND    MS1
         VM    EN
              RP1  (Vref)
         triangle DIAG/INDEX/VREF : NC
```

| Broche module | Connexion |
|---|---|
| VM | 12 V (trigger PD) |
| GND (les deux) | Masse commune |
| VIO | 3,3 V (ESP32) |
| M1A | **A+** noir (BLK) |
| M1B | **A−** bleu (BLU) |
| M2A | **B+** vert (GRN) |
| M2B | **B−** rouge (RED) |
| STEP | GPIO 4 |
| DIR | GPIO 5 |
| EN | GPIO 6 (actif bas) |
| **PDN** | GPIO 15, et GPIO 7 via **1 kΩ** |
| USART | NC — UART usine = **PDN** (4ᵉ broche depuis EN) |
| CLK | NC |
| MS1 / MS2 | GND / GND (adresse UART 0) |
| DIAG | NC — homing via UART (`SG_RESULT`) |
| RP1 | Vref (repli si pas d'UART) |

**PDN, pas USART.** Les deux existent sur ce module. L'UART usine est **PDN**
(4ᵉ broche en partant de EN). USART est la 5ᵉ, hors service sans modifier un
strap. Brancher GPIO 7/15 sur USART = driver muet.

**DIAG** n'est pas utilisé. Le homing StallGuard lit `SG_RESULT` sur l'UART
(PDN). Les 3 trous près de RP1 restent en l'air.

### Câble NEMA 17 (4 fils, UL1007 AWG26)

Côté moteur **PHR-6** (broches 2 et 5 vides) ; côté libre 4 fils (ou M20-4).

| Couleur | Signal | PHR-6 | TMC2209 |
|---|---|---|---|
| Noir | A+ | 1 | **M1A** |
| Vert | B+ | 3 | **M2A** |
| Bleu | A− | 4 | **M1B** |
| Rouge | B− | 6 | **M2B** |

Une bobine = une paire : noir+bleu (A), vert+rouge (B). Ne pas mélanger les
paires. Si le sens de rotation est inversé au premier essai, inverser **une**
paire (ex. M1A ↔ M1B) ou inverser DIR dans le firmware — pas les deux.

### Liaison UART à un fil

```
   ESP32 TX (GPIO 7) ──[ 1 kΩ ]──┬── PDN  (TWOTREES TMC2209 V2.0)
                                 │
   ESP32 RX (GPIO 15) ───────────┘
```

La résistance évite le conflit lorsque le driver répond. L'UART ne répond
que si **VM (12 V) et VIO (3,3 V)** sont présents. Sans cette liaison, il
faudrait régler le courant au potentiomètre et renoncer à StallGuard.

L'UART apporte :

1. **Réglage logiciel du courant**
2. **StealthChop2** (balayage silencieux, sans vibration parasite)
3. **StallGuard** (homing sans capteur)

### Courant moteur

Réglage recommandé : **700 mA RMS** par UART. En repli, multimètre :

$$V_{\text{ref}} \approx 1{,}25 \times I_{\text{RMS}} \approx 0{,}88\ \text{V}$$

(avec $R_{\text{sense}} = 0{,}11\ \Omega$ — vérifier sur la carte).

### StallGuard — paramètres de départ

| Registre | Valeur | Rôle |
|---|---|---|
| `TCOOLTHRS` | 0xFFFFF | StallGuard sur toute la plage |
| `SGTHRS` | 60 à 100 | Seuil (partir de 80) |
| Courant homing | 300 mA | Contact doux |
| Vitesse homing | 10 °/s | Minimum pour StallGuard |

---

## 6. Ordre de câblage recommandé

1. **Masses** : relier tous les GND (trigger, buck, ESP, TMC, LD19).  
2. **Mesurer** 12 V (trigger) et 5 V (buck) à vide.  
3. Brancher **5 V** sur ESP32 VIN et LD19 **P5V** (fil vert).  
4. Brancher **3,3 V** sur MPU6050 et TMC VIO.  
5. Signaux LD19 (TX blanc → GPIO 18, PWM noir ← GPIO 17).  
6. I2C MPU (8/9).  
7. TMC STEP/DIR/EN + UART sur **PDN** (1 kΩ).  
   Ne pas câbler USART, CLK ni DIAG.  
8. **12 V** sur TMC VM.  
9. Phases moteur en dernier (ou après un premier boot sans moteur).

---

## 7. Contrôle avant première mise sous tension

- [ ] Continuité des masses entre tous les modules
- [ ] Sortie du trigger PD mesurée à 12 V ± 0,5 V, **avant** de la relier
- [ ] Sortie du buck mesurée à 5 V ± 0,2 V, **avant** de la relier
- [ ] MPU6050 alimenté en 3,3 V, pas en 5 V
- [ ] LD19 TX bien vers ESP32 **RX** (erreur la plus fréquente)
- [ ] Résistance de 1 kΩ en place sur la ligne TX du TMC2209
- [ ] Courant du TMC2209 réglé bas avant le premier mouvement
- [ ] Câble du LiDAR avec du mou, libre sur ±90°
- [ ] Rien ne frotte lorsqu'on fait tourner la tête à la main

Premier démarrage : brancher **sans le moteur**, vérifier que le LD19 émet et
que le Wi-Fi monte, puis seulement connecter le moteur.

Voir aussi [build.md](build.md) étape 5 et [assembly.md](assembly.md).

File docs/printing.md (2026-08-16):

# Impression 3D

## Réglages généraux

| Paramètre | Valeur | Motif |
|---|---|---|
| Matériau | PETG | Rigidité et stabilité dimensionnelle |
| Buse | 0,4 mm | Standard |
| Hauteur de couche | 0,2 mm | Compromis précision / durée |
| Températures | 240 °C / 80 °C | À adapter au filament |
| Refroidissement | 40 % | Trop refroidir fragilise les couches en PETG |
| Rétraction | Selon profil PETG | Le PETG file facilement |

Le PLA convient pour un premier prototype, mais il flue sous contrainte et se
déforme dès 50 °C — proscrit dans une voiture en été.

## Réglages par pièce

| Pièce | Périmètres | Remplissage | Orientation | Supports |
|---|---|---|---|---|
| `test_fits` | **2** | **10 %** | Telle quelle | Non |
| `test_lidar_fit` | **2** | **10 %** | Telle quelle, rebord vers le haut | Non |
| `base_plate` | 4 | 30 % | **Retournée**, bossage vers le haut | Non |
| `bearing_tower` | **5** | **40 %** | Bride sur le plateau | Non |
| `lidar_cradle` | 4 | 35 % | **Couchée**, platine à plat | Sous le moyeu |
| `electronics_box` | 3 | 20 % | Ouverture vers le haut | Non |
| `electronics_lid` | 3 | 20 % | À plat | Non |

Durée totale : environ 9 h, pour 220 g de filament.

### `test_fits` — coupon rapide

Pièce **compacte** (~132 × 44 × 8 mm, logements roulement sur 5 mm).
Viser **20 à 30 min** de plateau :

| Paramètre | Valeur | Motif |
|---|---|---|
| Hauteur de couche | **0,28 mm** | Précision suffisante pour juger un Ø22 |
| Périmètres | **2** | Les perçages définissent l'ajustement, pas les parois |
| Remplissage | **10 %** | Plaque pleine, peu de contrainte mécanique |
| Vitesse | Profil « draft » du slicer | OK pour un coupon jetable |

Ne pas appliquer ces réglages agressifs à `bearing_tower` ni au berceau.

### `test_lidar_fit` — empreinte STL-19P

Coupon plat (~62 × 53 × 7,5 mm) pour valider le capteur **sans réimprimer le berceau**.

```bash
cd mechanical/openscad && make ../stl/test_lidar_fit.stl
```

Même couche 0,28 mm / 2 périmètres / 10 % que `test_fits`. Poser le STL-19P dans le rebord, **nappe vers la fente**. Contrôler : 3 vis M2,5, nappe qui sort, capteur sans forcer.

### `bearing_tower` — la pièce critique

Elle porte les deux roulements et définit à elle seule l'axe de rotation.
Toute souplesse ici se traduit directement en erreur angulaire, donc en erreur
de position dans le nuage. Ne pas réduire les 5 périmètres ni les 40 % de
remplissage.

Le cône se rétrécit vers le haut : aucune surface en surplomb, donc aucun
support. Les fenêtres hexagonales ont un sommet en pointe, auto-portant par
construction.

### `base_plate` — imprimée retournée

En posant la face supérieure sur le plateau, le bossage de trépied pointe vers
le haut et les lamages de vis moteur se retrouvent côté plateau. Résultat :
aucun surplomb, et surtout une **face de référence parfaitement plane** pour le
moteur, ce qui conditionne la perpendicularité de l'axe.

### `lidar_cradle` — couchée

Imprimer avec `rotate([0, -90, 0])`, platine à plat. Les couches sont ainsi
perpendiculaires à l'effort de porte-à-faux du LiDAR. Imprimée debout, la pièce
casserait au raccordement voile / platine.

## Étape obligatoire : calibrer les ajustements

**Imprimer `test_fits` en premier, avant toute autre pièce.**

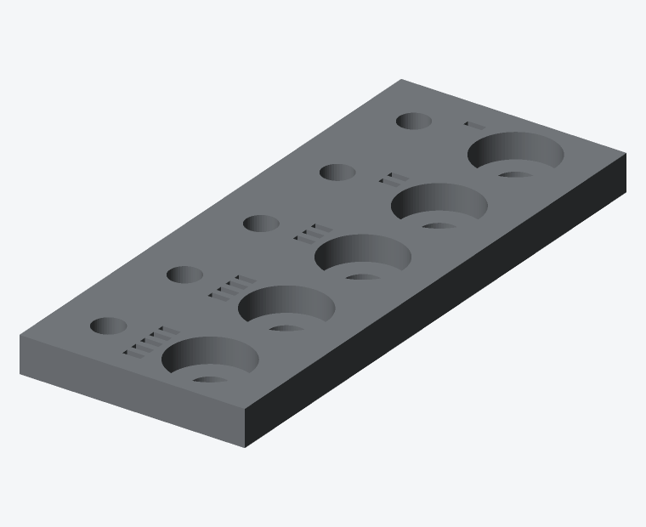
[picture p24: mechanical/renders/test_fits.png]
Coupon de calibration


Le coupon présente cinq logements de roulement (rangée du haut, borgnes, avec
trou d'expulsion) et cinq alésages de tige (rangée du bas, traversants). Chaque
paire est repérée par un nombre d'encoches gravées entre les deux rangées.

| Index | 1 | 2 | 3 | 4 | 5 |
|---|---|---|---|---|---|
| `delta` | −0,05 | 0,00 | +0,05 | +0,10 | +0,15 |
| Logement 608ZZ | 21,95 | 22,00 | 22,05 | 22,10 | 22,15 |
| Alésage tige Ø8 | 8,30 | 8,35 | 8,40 | 8,45 | 8,50 |

La plage est volontairement décalée vers le **large** : beaucoup d'imprimantes
rétrécissent les perçages. Si l'encoche 5 d'un ancien coupon (delta 0,00) était
encore serrée, repartir sur cette version avant d'imprimer la colonne.

Critères :

- **Roulement** : doit entrer à la presse à main ferme, sans jeu perceptible et
  sans faire blanchir ni fissurer la paroi. S'il entre tout seul, c'est trop
  large ; s'il faut un marteau, c'est trop serré. Le trou de Ø10 sous chaque
  logement permet de le ressortir sans l'abîmer.
- **Tige Ø8** : doit coulisser sans point dur, sans jeu radial sensible.

Reporter ensuite dans
[`params.scad`](../mechanical/openscad/params.scad) :

```
fit_press =  0.15;   // delta de l'index retenu pour le roulement
fit_slide =  0.45;   // delta + 0.35 pour l'index retenu pour la tige
```

puis régénérer les STL avec `make`. Une vingtaine de minutes de plateau
(compact + couche 0,28 mm) évitent de rater la colonne, qui demande près de 4 h.

## Pose de l'insert 1/4"-20

Utiliser un insert **1/4"-20 UNC × 10 × 8 mm** (diamètre extérieur Ø8 mm,
longueur 10 mm) — pas un 6×8 trop étroit pour le logement Ø8,4 × 13 mm.

1. Fer à souder à panne large, 230 °C (PETG) ou 210 °C (PLA).
2. Présenter l'insert, filetage vers l'extérieur, dans le logement Ø8,4 du
   bossage, **par le dessous**.
3. Enfoncer lentement et bien d'équerre, en s'aidant du chanfrein d'amorce.
   Compter 15 à 20 s.
4. S'arrêter **affleurant**, jamais en dessous : un insert trop enfoncé
   empêchera la vis de trépied de porter correctement.
5. Laisser refroidir sous une légère pression, à plat sur une surface de
   référence.

Un insert de travers rend le scanner impossible à mettre de niveau. En cas de
doute, le rechauffer et recommencer — le panier contient 50 inserts.

## Vérifications après impression

- [ ] Les deux 608ZZ entrent en force dans la colonne, sans jeu
- [ ] La tige Ø8 coulisse librement dans les deux roulements en place
- [ ] Le NEMA 17 se plaque sans jeu sur le plateau, bossage bien engagé
- [ ] La bride de colonne repose à plat sur le plateau (aucun basculement)
- [ ] L'insert 1/4"-20 est affleurant et d'équerre
- [ ] Le berceau serre fermement sur la tige, sans jeu de rotation
- [ ] Le rebord de centrage (**54 × 46,3 mm**) accueille le STL-19P sans forcer
- [ ] **3** vis M2,5 traversantes (2 à **10,77 mm** du bas / câble, 1 à **42,69 mm**, entraxe 31,92)
- [ ] Encoche câble **traversante** en bas de la platine (fente 16 mm, ouverte vers le bord)

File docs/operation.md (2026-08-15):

# Guide d'utilisation

## 1. Préparation des lieux

La préparation compte davantage que les réglages : la plupart des défauts d'un
relevé d'intérieur viennent de la scène, pas du capteur.

### Fenêtres — fermer les volets (recommandé)

Le STL-19P (**FHL-LD19P**) **détecte le verre** : le faisceau peut mesurer la
surface vitrée elle-même plutôt que de la traverser. Sans volet, on obtient
souvent un plan sur la vitre — parfois souhaitable, parfois confus selon
l'angle d'incidence.

Volets fermés, on obtient en plus :

1. Une surface opaque exploitable derrière la vitre (tablier du volet).
2. La suppression de l'éblouissement. Le capteur tolère 30 klux, alors qu'une
   tache de soleil direct dépasse 100 klux et provoque des décrochages locaux.

**Nuance** : même avec détection du verre, le tablier fermé peut apparaître
quelques centimètres en retrait si le faisceau le voit à travers une interstice.
Les fenêtres peuvent aussi montrer une double surface là où le faisceau arrive
perpendiculairement à la vitre (~4 % en spéculaire) ; le filtrage statistique
l'absorbe en général.

### Miroirs — les couvrir

C'est le problème le plus sérieux, et les volets n'y changent rien.

Un miroir ne produit pas du bruit : il produit une **pièce virtuelle complète
et géométriquement cohérente** derrière lui. Aucun filtrage d'aberrants ne la
supprimera, puisque ce ne sont pas des aberrations.

Couvrir d'un drap ou d'un carton pendant le scan. On récupère alors le plan du
miroir, ce que l'on veut. Penser également aux parois de douche, portes
vitrées, vitrines et façades d'armoires laquées.

### Autres surfaces délicates

| Surface | Effet | Parade |
|---|---|---|
| Inox, chrome, électroménager | Spéculaire, retour faible | Accepter les trous |
| Écrans TV éteints | Très peu réfléchissants | Couvrir |
| Sols brillants (carrelage) | Réflexion en incidence rasante | Scanner de plus près |
| Textiles noirs mats | Portée réduite | Se rapprocher |
| Végétation | Retours multiples | Filtrer en post-traitement |

### Occupants et animaux

Un scan dure 45 à 180 s. Tout ce qui bouge laisse des traînées. Faire sortir
les occupants de la pièce et fermer les portes des pièces non concernées.

## 2. Positionnement du scanner

### Nombre de positions

Une position par pièce ne suffit presque jamais : tout ce qui est derrière un
meuble ou un angle reste dans l'ombre. Compter :

- Petite pièce dégagée : 1 à 2 positions
- Pièce meublée : 3 à 4 positions
- Couloir : une position tous les 4 à 5 m
- Escalier : une position par palier, plus une à mi-volée

### Règles de placement

1. **Recouvrement** : au moins 30 % de zones communes entre deux positions
   voisines, faute de quoi le recalage ICP échouera.
2. **Ligne de vue** : chaque position doit voir la suivante.
3. **Hauteur** : environ 1,50 m, et **varier** entre positions — cela aide le
   recalage et comble le cône du nadir.
4. **Écarter des murs** : au moins 1 m, pour ne pas gâcher la moitié du champ.
5. **Sol stable** : éviter les planchers souples ; le moindre déplacement
   pendant le scan ruine la position.

### Cibles de recalage

Sur des surfaces pauvres en géométrie (couloir aux murs nus), disposer trois à
quatre objets asymétriques bien visibles depuis deux positions consécutives.
Une boîte, un carton, une chaise suffisent. Les laisser strictement immobiles
entre les scans.

## 3. Déroulement d'un scan

### Mise en station

1. Déployer le trépied, hauteur environ 1,50 m.
2. Visser le scanner sur l'embase 1/4"-20.
3. Mettre de niveau grossièrement à la bulle.
4. Mettre sous tension et attendre la connexion Wi‑Fi.
5. Ouvrir `http://lidar-scanner.local/` (ou l'IP du scanner).
6. Vérifier la section **Matériel** : Wi‑Fi, LiDAR, entraînement et IMU
   cohérents avec le câblage (pastilles OK ou alertes explicites).
7. Lancer la réception sur la station hôte, puis cliquer **Lancer le scan**.

Voir [web.md](web.md) pour la commande, les diagnostics et les réglages.

### Séquence d'un balayage

```
  1. Nivellement IMU        10 s   moyennage de la gravité
  2. Homing StallGuard       5 s   zéro d'azimut absolu
  3. Stabilisation STL-19P   3 s   montée en vitesse
  4. Balayage 0 → fin °  45-180 s  selon vitesse / amplitude
  5. Contrôle de choc        2 s   relecture de l'IMU
  6. Vidange des tampons     2 s
```

Le scanner ne démarre **pas** tout seul : chaque prise se lance depuis le
panneau (ou `POST /api/command?cmd=start`). Arrêt propre ou d'urgence depuis
la même page.

Ne pas toucher au trépied pendant le balayage — pas même pour le stabiliser.

### Choix du pas

| Pas $\psi$ | Durée | Points | Usage |
|---|---|---|---|
| 0,8° | 45 s | 225 000 | Reconnaissance, contrôle de couverture |
| 0,4° | 90 s | 450 000 | **Réglage standard** |
| 0,2° | 180 s | 900 000 | Relevé de détail, pièce unique |

Comptage à **5 000 pts/s** (STL-19P à 5 Hz). Voir [geometry.md](geometry.md) § 6.

## 4. Station hôte

### Visualisation en direct

```bash
cd host && source .venv/bin/activate
# WSL2 : export DISPLAY=:0 si besoin
lidar-visualize --port 9000
```

Le nuage se construit à l'écran pendant le balayage. Surveiller :

- Les murs doivent apparaître **plans**. S'ils sont courbes, le bras de levier
  est mal calibré ([calibration.md](calibration.md) § 1).
- Les angles doivent être **droits**.
- Aucune bande manquante hors du cône du nadir.

Guide détaillé Open3D (navigation, enregistrement, recalage, maillage, WSL) :
[open3d.md](open3d.md).

Sans matériel, le même pipeline se valide avec
`lidar-simulate --host 127.0.0.1 --port 9000 --fast` dans un second terminal.

### Enregistrement

```bash
lidar-receive --port 9000 --output scans/salon_pos1.pcd
```

Convention de nommage : `<pièce>_pos<n>.pcd`. Tenir un croquis papier des
positions : indispensable au recalage, et impossible à reconstituer après coup.

### Recalage multi-positions

```bash
lidar-register scans/salon_*.pcd --output salon_complet.pcd
```

Recalage grossier par appariement de caractéristiques, puis affinage ICP. Si
l'ICP diverge, c'est presque toujours un recouvrement insuffisant.

### Maillage et export

```bash
lidar-mesh salon_complet.pcd --output salon.ply --depth 8
```

Formats de sortie :

| Format | Usage |
|---|---|
| `.pcd` | Nuage de travail, Open3D / PCL |
| `.ply` | Maillage, import CAO |
| `.e57` | Échange standard en photogrammétrie |
| `.las` | SIG et gros volumes |

## 5. Ce qu'il faut attendre du résultat

| Usage | Adapté ? |
|---|---|
| Plan d'étage, surfaces | Oui, très bien |
| Volumes pour dimensionner une VMC ou un chauffage | Oui |
| Vérifier qu'un meuble passe | Oui |
| Modèle d'ambiance pour de la 3D | Oui |
| Détection de collisions en BIM | Non, précision insuffisante |
| Relevé patrimonial de détail | Non |
| Contrôle dimensionnel au millimètre | Non |

Précision réaliste : environ **±5 cm** sur un mur, avec un espacement des
points de 3 à 7 cm à 5 m. Un scanner terrestre professionnel atteint ±2 mm et
des dizaines de millions de points — pour 15 000 à 50 000 €.

## 6. Dépannage

| Symptôme | Cause probable | Correction |
|---|---|---|
| Murs incurvés | Bras de levier non calibré | Calibration § 1 |
| Nuage tourné / penché | Nivellement IMU raté | Refaire à l'arrêt complet |
| Arêtes dédoublées | Décalage temporel | Calibration § 5 |
| Bandes manquantes | Pas perdus au moteur | Baisser l'accélération, monter le courant |
| Points dans le jardin | Fenêtre sans volet | Fermer les volets |
| Pièce fantôme | Miroir | Le couvrir |
| Trous sur surfaces sombres | Réflectivité faible | Se rapprocher |
| Nuage bruité près du sol | Réflexion rasante | Normal, filtrer |
| Perte de paquets UDP | Wi-Fi saturé | Se rapprocher du point d'accès |
| Le scan s'arrête en cours | Coupure de la power bank | Vérifier le seuil de veille |
| Balayage bruyant | StealthChop non actif | Vérifier la liaison UART du TMC2209 |
| Pastille Entraînement Ko | TMC2209 absent ou EN relâché | Câblage UART GPIO 7/15 ; rehomer après estop |
| Pastille Entraînement Alerte | TMC OK, homing jamais fait | **Rehomer** depuis le panneau |
| MPU6050 Ko | I2C absent (GPIO 8/9) | Vérifier alim 3,3 V et adresse 0x68 |

## 7. Entretien

| Fréquence | Opération |
|---|---|
| Avant chaque scan | Nettoyer la fenêtre optique du STL-19P au chiffon microfibre |
| Mensuel | Vérifier le serrage du berceau et de l'accouplement |
| Mensuel | Contrôler l'usure du câble tournant |
| Semestriel | Refaire la calibration complète |
| Au besoin | Remplacer les 608ZZ (il en reste 38 au tiroir) |

Le STL-19P est donné pour plus de 10 000 h, soit largement au-delà d'un usage
amateur.

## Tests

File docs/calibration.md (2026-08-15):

# Calibration

Cinq mesures à effectuer une fois pour toutes. Elles conditionnent directement
la justesse du nuage : sans elles, le scanner produira un résultat
géométriquement cohérent mais faux.

## 1. Décalage optique du STL-19P ($t_x$)

**La mesure la plus importante.** C'est la distance entre la face de fixation du
STL-19P et son plan de balayage. Le berceau est dimensionné pour 22 mm ; la
valeur réelle doit être vérifiée.

Méthode directe :

1. Repérer visuellement la fente d'émission sur le pourtour de la tête
   rotative.
2. Mesurer au pied à coulisse la distance entre la face de fixation et le
   milieu de cette fente.
3. Comparer à `lidar_optical_offset = 22` dans `params.scad`.

Méthode par la mesure, plus fiable :

1. Monter le scanner et le mettre de niveau.
2. Placer un mur plat à distance connue $D$ (mesurée au mètre ruban depuis
   l'axe de rotation), perpendiculairement au faisceau.
3. Lancer un balayage de 180°.
4. Ajuster $t_x$ dans la configuration hôte jusqu'à ce que le mur soit **plan**
   dans le nuage.

Un $t_x$ erroné se voit immédiatement : les murs deviennent **incurvés**, avec
une courbure d'autant plus marquée que la surface est proche.

## 2. Zéro d'azimut

Le contact StallGuard définit le zéro mécanique, qui ne coïncide pas avec le
zéro souhaité pour le repère.

1. Lancer un homing.
2. Le scanner note l'orientation en butée.
3. Placer une cible verticale identifiable (piquet, arête de porte) dans une
   direction connue.
4. Relever le $\psi$ auquel elle apparaît dans le nuage.
5. Reporter l'écart dans `psi_offset`.

Répétabilité attendue : mieux que 0,5° sur dix homings. Au-delà, revoir
`SGTHRS` ou la rigidité du contrefort.

## 3. Pas par degré

En entraînement direct, la valeur théorique est :

$$\frac{200 \times 16}{360} = 8{,}889 \text{ micro-pas / degré}$$

Vérification pratique :

1. Homing.
2. Commander 3 200 micro-pas (soit un tour théorique).
3. Vérifier que le secteur de butée revient exactement au contact.

Un écart signale des pas perdus : réduire l'accélération ou augmenter le
courant.

## 4. Nivellement par l'IMU

Le MPU6050 est solidaire de la base fixe. Il ne mesure qu'une chose, mais il la
mesure bien : la direction de la gravité au repos.

Séquence, exécutée automatiquement au début de chaque scan :

1. Vérifier l'immobilité complète.
2. Acquérir 1 000 échantillons d'accéléromètre à 100 Hz (10 s).
3. Moyenner pour obtenir $\mathbf{g} = (g_x, g_y, g_z)$.
4. En déduire tangage et roulis de la base.
5. Construire $R_{\text{level}}$ et la stocker dans l'en-tête du scan.

Le moyennage sur 10 s réduit le bruit d'un facteur $\sqrt{1000} \approx 32$ :
d'environ 1° instantané à mieux que 0,05°. C'est précisément le régime où un
capteur bon marché devient exploitable.

**Étalonnage du montage.** L'IMU n'est jamais collée parfaitement d'équerre.
Une fois pour toutes :

1. Mettre le plateau de base rigoureusement de niveau (niveau à bulle de
   précision posé dessus, croisé à 90°).
2. Ouvrir le panneau web : section **Matériel** → **MPU6050** doit être **OK**.
3. Relever le triplet affiché `g=(gx, gy, gz)` (ou les champs JSON
   `imu_gx`, `imu_gy`, `imu_gz` via `/api/status`).
4. Reporter ces valeurs dans `host/calibration.json` sous la clé `g_zero`.

Toute mesure ultérieure s'exprime relativement à `g_zero`, ce qui élimine
l'erreur de collage.

**Détection de choc.** Pendant le scan, l'IMU est relue périodiquement. Si
$\mathbf{g}$ dérive de plus de 0,3°, le trépied a bougé : le scan est marqué
comme suspect. Un scan ainsi contaminé est irrécupérable, autant le savoir tout
de suite.

## 5. Synchronisation temporelle

En balayage continu, $\psi$ est interpolé à l'horodatage de chaque point. Un
retard constant $\Delta t$ entre la mesure LiDAR et la position moteur produit
un décalage angulaire proportionnel à la vitesse.

Mise en évidence :

1. Scanner un coin de pièce en balayant dans le **sens horaire**.
2. Refaire le même scan en **sens antihoraire**.
3. Superposer les deux nuages.

Un décalage angulaire entre les deux vaut $2 \times \omega \times \Delta t$.
Corriger `timestamp_offset_us` jusqu'à superposition.

C'est un défaut typiquement invisible sur un scan isolé, mais qui dédouble
proprement les arêtes dès qu'on recale deux scans entre eux.

## 6. Validation

| Test | Critère |
|---|---|
| Mur plat à 2 m | Épaisseur du nuage < 20 mm, aucune courbure |
| Coin de pièce | Angle mesuré 90° ± 1° |
| Hauteur sous plafond | Cohérente au mètre ruban à ±30 mm |
| Distance entre deux murs | Écart < 1 % de la mesure ruban |
| Sphère de couverture | Aucune bande manquante hors cône du nadir |
| Aller-retour | Superposition à mieux que 20 mm |

Ajuster les paramètres Open3D de post-traitement :

| Traitement | Paramètres de départ |
|---|---|
| Suppression d'aberrants statistique | `nb_neighbors=20`, `std_ratio=2.0` |
| Sous-échantillonnage voxel (aperçu) | `voxel_size=0.01` |
| Estimation des normales | `radius=0.1`, `max_nn=30` |
| Reconstruction Poisson | `depth=8` |

## 7. Fichier de calibration

Les valeurs sont regroupées dans `host/calibration.json`, appliquées au
post-traitement. Elles restent ainsi modifiables **sans reflasher ni
rescanner** — c'est tout l'intérêt de transmettre les données en polaire brut.

```json
{
  "lever_arm_mm": { "tx": 0.0, "ty": 0.0, "tz": 0.0 },
  "psi_offset_deg": 0.0,
  "theta_offset_deg": 0.0,
  "steps_per_degree": 8.889,
  "timestamp_offset_us": 0,
  "g_zero": [0.0, 0.0, -1.0]
}
```

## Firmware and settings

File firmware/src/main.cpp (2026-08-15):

/**
 * Scanner 3D LiDAR DIY — firmware ESP32-S3
 *
 * Le LD19 est monté sur la tranche : son plan de balayage est vertical
 * et contient l'axe de rotation. L'angle interne du LiDAR est donc
 * l'ÉLÉVATION, et l'angle moteur l'AZIMUT. Voir docs/geometry.md.
 *
 * Les points partent en POLAIRE BRUT ; la conversion cartésienne est
 * faite côté hôte, où la calibration reste modifiable après coup.
 *
 * Tâches :
 *   lidar_task    cœur 1  UART LD19 -> file de points
 *   network_task  cœur 0  agrégation -> datagrammes UDP
 *   motion_task   cœur 1  commandes start/stop/rehome/estop
 *   web_task      cœur 0  panneau web + OTA (voir ota.cpp)
 */

#include <Arduino.h>
#include <WiFi.h>
#include <WiFiUdp.h>
#include <esp_timer.h>

#include "config.h"
#include "control.h"
#include "ld19.h"
#include "mpu6050.h"
#include "ota.h"
#include "protocol.h"
#include "scanner.h"
#include "settings.h"
#include "status.h"
#include "wifi_setup.h"

namespace {

WiFiUDP udp;
NetworkSettings net_settings;

QueueHandle_t point_queue = nullptr;
TaskHandle_t lidar_task_handle = nullptr;
TaskHandle_t network_task_handle = nullptr;

uint32_t packet_sequence = 0;
volatile uint16_t lidar_speed_dhz = 0;
volatile uint16_t pending_flags = 0;

volatile bool ota_lock = false;

struct QueuedPoint {
    RawPoint pt;
    uint64_t t_us;
    int32_t psi_mdeg;
};

Ld19Parser g_parser;

bool imuAbortRequested() {
    ScanCommand pending;
    if (!controlTryRecv(pending)) return false;
    if (pending == ScanCommand::EStop) {
        scannerEmergencyStop();
        return true;
    }
    return pending == ScanCommand::Stop;
}

bool pollScanShock(const float g_ref[3]) {
    if (!mpu6050Ready()) return false;
    if (!mpu6050DetectShock(g_ref)) return false;
    pending_flags |= PKT_FLAG_SHOCK_DETECTED;
    mpu6050SetShockFlag(true);
    Serial.println("[main] choc détecté — scan suspect");
    return true;
}

void pollScanCommands(bool &estop, bool &stop) {
    ScanCommand pending;
    while (controlTryRecv(pending)) {
        if (pending == ScanCommand::EStop) estop = true;
        if (pending == ScanCommand::Stop) stop = true;
    }
}

void lidarTask(void*) {
    g_parser.begin();
    Ld19Frame frame;

    for (;;) {
        while (Serial1.available()) {
            if (!g_parser.feed(static_cast<uint8_t>(Serial1.read()), frame)) continue;

            lidar_speed_dhz = static_cast<uint16_t>(frame.speed_dps / 36);
            statusSetLidarStats(g_parser.framesOk(), g_parser.framesBad(),
                                lidar_speed_dhz);
            const uint64_t now = esp_timer_get_time();
            const int32_t psi = scannerPsiMdeg();

            for (int i = 0; i < LD19_POINTS_PER_FRAME; i++) {
                if (frame.points[i].distance_mm == 0) continue;

                QueuedPoint q;
                q.pt.rho_mm = frame.points[i].distance_mm;
                q.pt.theta_cdeg = frame.points[i].angle_cdeg;
                q.pt.intensity = frame.points[i].intensity;
                q.pt.reserved = 0;
                q.pt.dt_us = 0;
                q.t_us = now;
                q.psi_mdeg = psi;
                xQueueSend(point_queue, &q, 0);
            }
        }
        statusSetQueueDepth(uxQueueMessagesWaiting(point_queue));
        vTaskDelay(1);
    }
}

void networkTask(void*) {
    static uint8_t buffer[sizeof(PacketHeader) + POINTS_PER_PACKET * sizeof(RawPoint)];
    QueuedPoint q;

    for (;;) {
        uint16_t count = 0;
        uint64_t t_start = 0;
        int32_t psi_start = 0, psi_end = 0;

        while (count < POINTS_PER_PACKET) {
            const TickType_t wait = (count == 0) ? pdMS_TO_TICKS(200) : 0;
            if (xQueueReceive(point_queue, &q, wait) != pdTRUE) break;

            if (count == 0) {
                t_start = q.t_us;
                psi_start = q.psi_mdeg;
            }
            psi_end = q.psi_mdeg;

            const uint64_t delta = q.t_us - t_start;
            q.pt.dt_us = static_cast<uint16_t>(delta > 65535 ? 65535 : delta);

            memcpy(buffer + sizeof(PacketHeader) + count * sizeof(RawPoint), &q.pt,
                   sizeof(RawPoint));
            count++;
        }

        if (count == 0 || WiFi.status() != WL_CONNECTED) continue;

        PacketHeader h{};
        h.magic = PACKET_MAGIC;
        h.version = PROTOCOL_VERSION;
        h.flags = pending_flags;
        h.sequence = packet_sequence++;
        h.point_count = count;
        h.lidar_speed_dhz = lidar_speed_dhz;
        h.t_start_us = t_start;
        h.psi_start_mdeg = psi_start;
        h.psi_end_mdeg = psi_end;
        pending_flags = 0;
        memcpy(buffer, &h, sizeof(h));

        udp.beginPacket(net_settings.udp_host.c_str(), UDP_PORT);
        udp.write(buffer, sizeof(PacketHeader) + count * sizeof(RawPoint));
        udp.endPacket();
        statusSetPackets(packet_sequence);
    }
}

bool runScanSequence() {
    if (ota_lock) {
        Serial.println("[main] balayage refusé : OTA en cours");
        return false;
    }

    scannerEnable();
    pending_flags |= PKT_FLAG_SCAN_START;
    mpu6050SetShockFlag(false);

    float g_ref[3] = {0.0f, 0.0f, -1.0f};
    if (mpu6050Ready()) {
        scannerSetState(ScanState::Levelling);
        if (!mpu6050MeasureLevel(g_ref, imuAbortRequested)) {
            Serial.println("[main] nivellement IMU échoué");
            pending_flags |= PKT_FLAG_SCAN_END;
            scannerSetState(ScanState::Fault);
            return false;
        }
        pending_flags |= PKT_FLAG_LEVEL_VALID;
        mpu6050StoreLevelRef(g_ref);
    } else {
        Serial.println("[main] IMU absent — nivellement ignoré");
    }

    if (!scannerHome()) {
        Serial.println("[main] homing échoué");
        pending_flags |= PKT_FLAG_SCAN_END;
        return false;
    }

    // Une commande Stop/EStop pendant le homing a pu arriver.
    ScanCommand pending;
    while (controlTryRecv(pending)) {
        if (pending == ScanCommand::EStop) {
            scannerEmergencyStop();
            pending_flags |= PKT_FLAG_SCAN_END;
            return false;
        }
        if (pending == ScanCommand::Stop) {
            pending_flags |= PKT_FLAG_SCAN_END;
            scannerSetState(ScanState::Idle);
            return false;
        }
    }

    Serial.println("[main] montée en vitesse du LiDAR");
    scannerSetState(ScanState::Spinup);
    for (int i = 0; i < 30; i++) {
        bool estop = false, stop = false;
        pollScanCommands(estop, stop);
        if (estop) {
            pending_flags |= PKT_FLAG_SCAN_END;
            return false;
        }
        if (stop) {
            scannerSetState(ScanState::Idle);
            pending_flags |= PKT_FLAG_SCAN_END;
            return false;
        }
        if (mpu6050HasLevelRef()) pollScanShock(g_ref);
        vTaskDelay(pdMS_TO_TICKS(100));
    }

    scannerStartSweep();
    uint32_t last_shock_ms = millis();
    while (scannerState() == ScanState::Scanning) {
        bool estop = false, stop = false;
        pollScanCommands(estop, stop);
        if (estop) {
            scannerEmergencyStop();
            pending_flags |= PKT_FLAG_SCAN_END;
            return false;
        }
        if (stop) scannerRequestStop();
        if (mpu6050HasLevelRef() && millis() - last_shock_ms >= 100) {
            last_shock_ms = millis();
            pollScanShock(g_ref);
        }
        scannerTick();
        taskYIELD();
    }

    if (mpu6050HasLevelRef()) {
        Serial.println("[main] contrôle IMU post-balayage");
        const uint32_t t0 = millis();
        while (millis() - t0 < 2000) {
            pollScanShock(g_ref);
            bool estop = false, stop = false;
            pollScanCommands(estop, stop);
            if (estop) {
                scannerEmergencyStop();
                pending_flags |= PKT_FLAG_SCAN_END;
                return false;
            }
            vTaskDelay(pdMS_TO_TICKS(50));
        }
    }

    pending_flags |= PKT_FLAG_SCAN_END;
    if (scannerState() == ScanState::Done) scannerSetState(ScanState::Idle);
    Serial.println("[main] scan terminé");
    return true;
}

void motionTask(void*) {
    // Au démarrage on reste au repos : l'OTA et le panneau web sont
    // immédiatement joignables. Plus de balayage automatique — un scan
    // se lance depuis http://lidar-scanner.local/
    Serial.println("[main] en attente de commande (web / API)");
    scannerSetState(ScanState::Idle);

    for (;;) {
        const ScanCommand cmd = controlWait();
        if (ota_lock && cmd != ScanCommand::EStop) {
            Serial.println("[main] commande ignorée : OTA en cours");
            continue;
        }

        switch (cmd) {
            case ScanCommand::Start:
                runScanSequence();
                break;
            case ScanCommand::Rehome:
                scannerEnable();
                if (scannerHome()) scannerSetState(ScanState::Idle);
                break;
            case ScanCommand::Stop:
                scannerRequestStop();
                break;
            case ScanCommand::EStop:
                scannerEmergencyStop();
                break;
        }
    }
}

bool otaIsBusy() {
    switch (scannerState()) {
        case ScanState::Homing:
        case ScanState::Spinup:
        case ScanState::Scanning:
            return true;
        default:
            return false;
    }
}

void otaOnBegin() {
    ota_lock = true;
    controlSend(ScanCommand::EStop);
    scannerEmergencyStop();
    if (lidar_task_handle) vTaskSuspend(lidar_task_handle);
    if (network_task_handle) vTaskSuspend(network_task_handle);
}

void otaOnAbort() {
    if (lidar_task_handle) vTaskResume(lidar_task_handle);
    if (network_task_handle) vTaskResume(network_task_handle);
    ota_lock = false;
    Serial.println("[main] mise à jour abandonnée");
}

}  // namespace

void setup() {
    Serial.begin(115200);
    delay(500);
    Serial.printf("\n[lidar-scanner] démarrage — firmware %s\n", FIRMWARE_VERSION);

    settingsLoad();

    Serial1.begin(LIDAR_BAUD, SERIAL_8N1, LIDAR_RX_PIN, -1);
    Serial1.setRxBufferSize(4096);

    scannerInit();
    settingsApplyHardware();
    mpu6050Init();

    wifiCheckResetButton();
    if (!wifiSetup(net_settings)) {
        Serial.println("[wifi] redémarrage dans 3 s");
        delay(3000);
        ESP.restart();
    }
    udp.begin(UDP_PORT);

    controlInit();
    otaInit(OTA_HOSTNAME, net_settings.ota_password,
            OtaHooks{otaIsBusy, otaOnBegin, otaOnAbort});

    point_queue = xQueueCreate(2048, sizeof(QueuedPoint));
    if (!point_queue) {
        Serial.println("[main] création de la file impossible");
        ESP.restart();
    }

    xTaskCreatePinnedToCore(lidarTask, "lidar", 4096, nullptr, 5, &lidar_task_handle,
                            1);
    xTaskCreatePinnedToCore(networkTask, "network", 4096, nullptr, 3,
                            &network_task_handle, 0);
    xTaskCreatePinnedToCore(motionTask, "motion", 4096, nullptr, 4, nullptr, 1);

    Serial.println("[lidar-scanner] prêt — ouvrir http://lidar-scanner.local/");
}

void loop() {
    static uint32_t last = 0;
    if (millis() - last > 2000) {
        last = millis();
        const DeviceStatus d = statusSnapshot();
        Serial.printf("[stat] %s  psi=%.2f  LiDAR=%.1fHz  file=%u  crc=%u/%u%s\n",
                      scanStateName(d.state), d.psi_deg, d.lidar_hz_meas,
                      static_cast<unsigned>(d.queue_depth),
                      static_cast<unsigned>(d.frames_ok),
                      static_cast<unsigned>(d.frames_bad),
                      otaInProgress() ? "  [OTA]" : "");
    }
    vTaskDelay(pdMS_TO_TICKS(100));
}

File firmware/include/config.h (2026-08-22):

#pragma once

// ============================================================
//  Scanner 3D LiDAR — configuration du firmware
//  Voir docs/wiring.md pour la justification du brochage.
// ============================================================

#define FIRMWARE_VERSION "0.4.5"

// ---- WiFiManager : portail captif, aucun identifiant en dur ----
#define WIFIMANAGER_AP_NAME "LiDAR-Scanner-Setup"
#define WIFIMANAGER_AP_PASSWORD ""
#define WIFIMANAGER_PORTAL_TIMEOUT_S 180
#define WIFIMANAGER_CONNECT_TIMEOUT_S 20
#define WIFI_RESET_PIN 0  // bouton BOOT : maintenu au démarrage = reset Wi-Fi

// ---- Mise à jour par le réseau (OTA) ----
// Le mot de passe se configure dans le portail WiFiManager et est
// persisté en NVS. La valeur ci-dessous n'est qu'un repli au premier
// démarrage : la changer est vivement conseillé.
#define OTA_HOSTNAME "lidar-scanner"
#define OTA_PASSWORD_DEFAULT "lidar-ota"
#define OTA_PORT 3232
#define OTA_WEB_PORT 80

// L'OTA est volontairement injoignable pendant un balayage : flasher en
// pleine acquisition perdrait le scan et laisserait la mécanique dans un
// état indéterminé. Mettre à 1 pour passer outre.
#define OTA_ALLOW_DURING_SCAN 0

// Délai d'attente avant le premier balayage, pendant lequel l'OTA est
// joignable. C'est le filet de sécurité : sans lui, un firmware qui
// plante en cours de scan ne serait plus récupérable que par USB.
#define OTA_BOOT_WINDOW_S 10

// ---- Diffusion UDP ----
#define UDP_HOST_DEFAULT "192.168.1.100"
#define UDP_PORT 9000
#define POINTS_PER_PACKET 120  // 120 x 8 o + 32 o d'en-tête = 992 o < MTU

// ---- LiDAR LD19 (UART1) ----
// ATTENTION : ne pas utiliser les GPIO 33-37, occupés par la PSRAM
// octale de la variante N16R8.
#define LIDAR_RX_PIN 18
#define LIDAR_PWM_PIN 17
#define LIDAR_BAUD 230400
#define LIDAR_TARGET_HZ 5.0f  // 5 Hz : double la résolution angulaire

// ---- MPU6050 (I2C) — monté sur la base FIXE ----
#define I2C_SDA_PIN 8
#define I2C_SCL_PIN 9
#define MPU6050_ADDR 0x68
#define MPU6050_SAMPLE_HZ 100
#define MPU6050_LEVEL_SAMPLES 1000  // 10 s à 100 Hz
#define MPU6050_STABLE_CHECK_SAMPLES 50
#define MPU6050_STABLE_MAX_DEV_G 0.02f  // écart-type instantané max (~0,02 g)
#define MPU6050_SHOCK_DEG 0.3f

// ---- TMC2209 ----
#define STEP_PIN 4
#define DIR_PIN 5
#define EN_PIN 6
#define TMC_TX_PIN 7   // via résistance 1 kOhm vers PDN (TWOTREES V2.0, pas USART)
#define TMC_RX_PIN 15
#define TMC_ADDRESS 0

#define MICROSTEPS 16
#define STEPS_PER_REV (200 * MICROSTEPS)          // 3200
#define STEPS_PER_DEGREE (STEPS_PER_REV / 360.0f) // 8.889

#define CURRENT_SCAN_MA 700
#define CURRENT_HOMING_MA 300

// ---- Profil de balayage ----
// 180 deg suffisent : le plan a psi et celui a psi+180 sont identiques,
// donc la sphere est couverte exactement une fois. Voir docs/geometry.md.
#define SCAN_START_DEG 0.0f
#define SCAN_END_DEG 180.0f
#define SCAN_SPEED_DEG_S 2.0f
#define HOMING_SPEED_DEG_S 10.0f
#define STALLGUARD_THRESHOLD 80

// ---- Protocole ----
#define PACKET_MAGIC 0x4C444152  // "LDAR"
#define PROTOCOL_VERSION 2

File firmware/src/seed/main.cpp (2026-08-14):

/**
 * Amorce OTA — premier firmware à flasher en USB.
 *
 * Ne pilote ni le LiDAR ni le moteur. Sert uniquement à :
 *   - configurer le Wi-Fi (même portail / NVS que le firmware scanner)
 *   - accepter une mise à jour OTA du firmware (app0/app1)
 *   - accepter une mise à jour OTA du filesystem (LittleFS)
 *
 * Ensuite : pio run -e ota -t upload  et  pio run -e ota -t uploadfs
 * plus besoin de câble USB.
 */

#include <Arduino.h>
#include <ArduinoOTA.h>
#include <ESPmDNS.h>
#include <LittleFS.h>
#include <Update.h>
#include <WebServer.h>
#include <WiFi.h>
#include <esp_ota_ops.h>

#include "config.h"
#include "wifi_setup.h"

#define SEED_VERSION "0.1.1-seed"

namespace {

WebServer server(OTA_WEB_PORT);
NetworkSettings net_settings;

volatile bool in_progress = false;
bool upload_authorized = false;
bool upload_refused = false;
int upload_command = U_FLASH;
bool fs_mounted = false;

bool mountLittleFS() {
    if (LittleFS.begin(false)) {
        fs_mounted = true;
        return true;
    }
    Serial.println("[seed] LittleFS illisible — formatage");
    if (LittleFS.format() && LittleFS.begin(true)) {
        fs_mounted = true;
        return true;
    }
    fs_mounted = false;
    return false;
}

const char kIndexHtml[] PROGMEM = R"HTML(<!DOCTYPE html>
<html lang="fr">
<head>
<meta charset="utf-8">
<meta name="viewport" content="width=device-width,initial-scale=1">
<title>Amorce OTA — LiDAR</title>
<style>
:root{color-scheme:dark;--bg:#14161a;--card:#1c1f24;--line:#2a2e35;--muted:#8b929c;
--text:#e6e8eb;--acc:#4a90d9;--ok:#5aa469;--warn:#d9a441;--err:#e06c6c}
*{box-sizing:border-box}
body{margin:0;background:var(--bg);color:var(--text);
font:14px/1.5 system-ui,-apple-system,Segoe UI,Roboto,sans-serif}
header{padding:18px 20px 8px;max-width:640px;margin:0 auto}
header h1{margin:0;font-size:18px;letter-spacing:-.01em}
header .sub{color:var(--muted);font-size:12.5px;margin-top:2px}
main{max-width:640px;margin:0 auto;padding:8px 16px 40px;display:grid;gap:14px}
section{background:var(--card);border:1px solid var(--line);border-radius:12px;padding:16px 18px}
section h2{margin:0 0 12px;font-size:13px;text-transform:uppercase;letter-spacing:.04em;color:var(--muted);font-weight:600}
dl.grid{display:grid;grid-template-columns:auto 1fr;gap:6px 16px;margin:0;font-size:13px;font-variant-numeric:tabular-nums}
dt{color:var(--muted)} dd{margin:0}
.hint{font-size:12px;color:var(--muted);margin:0 0 12px}
.msg{min-height:18px;font-size:13px;margin-top:10px}
.ok{color:var(--ok)} .err{color:var(--err)} .warn{color:var(--warn)}
.drop{border:1.5px dashed var(--line);border-radius:10px;padding:20px;text-align:center;cursor:pointer;display:block}
.drop:hover,.drop.over{border-color:var(--acc);background:#1f2530}
.drop input{display:none}
.name{margin-top:8px;font-size:12.5px;color:var(--acc);word-break:break-all}
.bar{height:6px;margin-top:12px;border-radius:4px;background:#2a2e35;overflow:hidden;display:none}
.bar i{display:block;height:100%;width:0;background:var(--ok)}
button{border:0;border-radius:8px;padding:10px 14px;font:inherit;font-weight:600;cursor:pointer;background:var(--acc);color:#fff;width:100%;margin-top:12px}
button:disabled{opacity:.45;cursor:not-allowed}
ul.files{margin:0;padding:0;list-style:none;font-size:13px}
ul.files li{display:flex;justify-content:space-between;gap:12px;padding:4px 0;border-bottom:1px solid var(--line)}
ul.files span{color:var(--muted);font-variant-numeric:tabular-nums}
</style>
</head>
<body>
<header>
  <h1>Amorce OTA</h1>
  <div class="sub">v<span id="ver">…</span> · <span id="ip">…</span> · plus besoin d'USB</div>
</header>
<main>
<section>
  <h2>État</h2>
  <p class="hint">Ce firmware ne scanne pas. Il sert à pousser le firmware scanner et le filesystem par le réseau.</p>
  <dl class="grid">
    <dt>Rôle</dt><dd>amorce</dd>
    <dt>Partition app</dt><dd id="app">…</dd>
    <dt>Cible OTA</dt><dd id="next">…</dd>
    <dt>LittleFS</dt><dd id="fs">…</dd>
    <dt>Wi‑Fi / heap</dt><dd id="net">…</dd>
  </dl>
</section>
<section>
  <h2>Fichiers LittleFS</h2>
  <ul class="files" id="files"><li>…</li></ul>
</section>
<section>
  <h2>Firmware applicatif</h2>
  <p class="hint">Fichier <code>firmware.bin</code> — <code>pio run -e usb</code> ou <code>-e ota</code>.</p>
  <label class="drop" id="dropfw">
    <input type="file" id="filefw" accept=".bin">
    Déposer le firmware ou cliquer
    <div class="name" id="namefw"></div>
  </label>
  <button id="flashfw" disabled>Téléverser le firmware</button>
  <div class="bar" id="barfw"><i id="fillfw"></i></div>
  <div class="msg" id="msgfw"></div>
</section>
<section>
  <h2>Filesystem LittleFS</h2>
  <p class="hint">Fichier <code>littlefs.bin</code> — <code>pio run -e ota -t uploadfs</code>.</p>
  <label class="drop" id="dropfs">
    <input type="file" id="filefs" accept=".bin">
    Déposer l'image filesystem ou cliquer
    <div class="name" id="namefs"></div>
  </label>
  <button id="flashfs" disabled>Téléverser le filesystem</button>
  <div class="bar" id="barfs"><i id="fillfs"></i></div>
  <div class="msg" id="msgfs"></div>
</section>
</main>
<script>
const $=id=>document.getElementById(id);
function setMsg(id,text,cls){const e=$(id);e.textContent=text||'';e.className='msg '+(cls||'')}
function bindDrop(dropId,fileId,nameId,btnId){
  const drop=$(dropId);
  ['dragover','dragleave','drop'].forEach(e=>drop.addEventListener(e,ev=>{
    ev.preventDefault(); drop.classList.toggle('over',e==='dragover');
    if(e==='drop'&&ev.dataTransfer.files.length){$(fileId).files=ev.dataTransfer.files;pick()}
  }));
  $(fileId).onchange=pick;
  function pick(){
    const f=$(fileId).files[0]; if(!f)return;
    $(nameId).textContent=f.name+' ('+(f.size/1024).toFixed(0)+' ko)';
    $(btnId).disabled=false;
  }
}
function bindFlash(fileId,btnId,barId,fillId,msgId,url){
  $(btnId).onclick=()=>{
    const f=$(fileId).files[0]; if(!f)return;
    const fd=new FormData(); fd.append('image',f,f.name);
    const xhr=new XMLHttpRequest();
    $(btnId).disabled=true; $(barId).style.display='block';
    setMsg(msgId,'Écriture en flash…','warn');
    xhr.upload.onprogress=e=>{if(e.lengthComputable)$(fillId).style.width=(e.loaded/e.total*100).toFixed(1)+'%'};
    xhr.onload=()=>{
      const ok=xhr.status===200;
      setMsg(msgId,ok?'Réussi — redémarrage.':('Échec : '+xhr.responseText),ok?'ok':'err');
      if(!ok)$(btnId).disabled=false;
    };
    xhr.onerror=()=>{setMsg(msgId,'Connexion interrompue.','err');$(btnId).disabled=false};
    xhr.open('POST',url); xhr.send(fd);
  };
}
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

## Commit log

2026-08-12 Initial commit: scanner 3D LiDAR DIY
    Documentation, firmware ESP32-S3 (WiFiManager, streaming UDP) et station hôte Python.
2026-08-12 Corrige la géométrie de balayage et ajoute la conception mécanique complète
    La transformation initiale traitait l'angle interne du LiDAR comme l'azimut
    et l'angle moteur comme l'élévation, ce qui décrit une rotule pan-tilt et non
    un plan de balayage mis en rotation : à 90° d'élévation, le scan entier
    s'effondrait au zénith. L'architecture passe à un plan de balayage vertical
    tournant autour d'un axe vertical, seule géométrie qui place les pôles
    d'échantillonnage au zénith et au nadir plutôt que sur deux murs quelconques.
    Le MPU6050 passe de la nacelle mobile à la base fixe : son bruit de 0,5 à 1°
    dégraderait d'un facteur 2 à 4 la référence angulaire du moteur (0,11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
    [assembly.scad, base_plate.scad, base_plate.stl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]
2026-08-12 Ajoute la mise à jour du firmware par le réseau (OTA)
    Le port USB devient peu accessible une fois le scanner sanglé sur son
    trépied : les mises à jour passent désormais par le Wi-Fi, via espota
    pour le développement et via une page web authentifiée sur le terrain.
    Trois garde-fous, l'OTA pouvant sinon laisser l'appareil en mauvais état :
    - le moteur est coupé avant la première écriture en flash, sans quoi le
    redémarrage laisserait l'axe en couple ;
    - l'OTA est refusé pendant un balayage, qui serait perdu ;
    - une fenêtre de 10 s au démarrage garantit qu'un firmware plantant en
    cours de scan reste rattrapable sans rebrancher l'USB.
    Corrige au passage la perte des réglag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
    [config.h, main.cpp, ota.cpp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]
2026-08-12 Ajoute le panneau web de commande, diagnostics et réglages
    Le scanner ne fait plus un scan unique au démarrage : motion_task attend
    des commandes (start/stop/rehome/estop) via une file FreeRTOS, pilotables
    depuis http://lidar-scanner.local/ sur le même serveur que l'OTA.
    Les six paramètres de mise au point (StallGuard, courants, vitesse,
    amplitude, fréquence LiDAR) sont bornés côté firmware, persistés en NVS
    et appliqués à chaud hors balayage. La télémétrie live (CRC, ψ, SG, file,
    RSSI) remplace la console série pour le réglage sur trépied.
    La calibration géométrique reste volontairement hors panneau, côté hôte.
    [config.h, main.cpp, ota.cpp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]
2026-08-12 Ajoute lidar-simulate : flux UDP synthétique pour valider l'hôte
    Génère une pièce rectangulaire par lancer de rayons, encode le protocole
    v2 du firmware et l'envoie en UDP. Permet de tester visualize / receive
    sans LiDAR ni ESP32.
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2026-08-12 Corrige lidar-visualize sous WSL sans DISPLAY
    Exporte DISPLAY=:0 si WSLg est présent, et bascule en réception
    headless avec message clair si la fenêtre GLFW échoue encore.
2026-08-12 Met à jour la doc hôte : simulateur, WSL et démarrage rapide
    Aligne README, host/README, operation et PROJECT sur lidar-simulate,
    DISPLAY=:0 sous WSL, et le compteur de tests à jour.
2026-08-12 Ajoute le guide de construction pas à pas (docs/build.md)
    Parcours ordonné de la commande au premier scan, avec contrôles de
    passage et liens vers les fiches détaillées déjà existantes.
2026-08-12 Corrige l'inventaire du guide : sections A–E alignées sur le BOM
    La checklist sautait de B à D et omettait les pièces imprimées (C).
2026-08-12 Corrige le rendu Markdown de l'étape 7 (liste Coupée)
    La suite « besoin) » passait sur une nouvelle ligne indentée et cassait
    l'affichage de la checklist.
2026-08-12 Enregistre le nuage simulé en .pcd depuis lidar-simulate
    Par défaut écrit scans/simulate.pcd (même chaîne parse/transform que
    l'hôte). Options --no-save, --no-udp et --output pour UDP seul ou fichier
    seul.
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2026-08-12 Versionne un scan simulé d'exemple (scans/simulate.pcd)
    Exception gitignore pour ce fichier ; les autres .pcd restent ignorés.
    Permet d'ouvrir un nuage Open3D sans relancer lidar-simulate.
2026-08-12 Enrichit la simulation : appartement en L avec mobilier
    Scène par défaut « apartment » (salon, couloir, porte, canapé, table,
    bibliothèque, îlot, colonne). --scene box conserve le pavé vide.
    Régénère scans/simulate.pcd (~400 k points).
2026-08-12 Ajoute les plans de câblage SVG et enrichit wiring.md
    Quatre schémas vectoriels (ensemble, alimentation, signaux, brochage),
    générateur Python, diagrammes Mermaid et ordre de câblage recommandé.
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2026-08-12 Versionne le maillage simulé scans/simulate.ply
    Exception gitignore pour ce .ply d'exemple ; les autres restent ignorés.
2026-08-12 Ajoute le lissage de maillage à lidar-mesh (Taubin par défaut)
    Options --smooth et --smooth-iter ; accepte aussi un .ply déjà produit
    pour le relisser sans refaire Poisson.
2026-08-14 Ajoute une amorce OTA USB et le support LittleFS pour éviter le recâblage.
    Le premier flash installe un firmware minimal (Wi-Fi + OTA firmware/filesystem) ; le scanner arrive ensuite par le réseau. Inclut la définition N16R8 et la mise à jour de la doc.
2026-08-14 Calibre les ajustements d'impression et compacte le coupon test_fits.
    Décale la plage de calibration vers le large pour les perçages serrés, met à jour fit_press/fit_slide, et regénère les STL avec le coupon optimisé pour une impression rapide.
    [base_plate.stl, bearing_tower.stl, electronics_box.stl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]
2026-08-14 Corrige le débordement du logement roulement sur test_fits.
    Élargit le coupon à 132 mm avec marges calculées pour que la colonne 5 ne soit plus tronquée, et regénère le STL.
    [test_fits.scad, test_fits.stl]
2026-08-14 Durcit l'amorce OTA au premier boot.
    Formate LittleFS avant le Wi-Fi si la partition est illisible, évite les erreurs NVS bruyantes, et ne touche plus au FS quand il est absent.
2026-08-14 Calibre fit_press et fit_slide d'après le coupon test_fits.
    Encoche 5 pour le roulement (Ø22,15) et encoche 4 pour la tige (Ø8,45) ; regénère bearing_tower et lidar_cradle.
    [bearing_tower.stl, lidar_cradle.stl, params.scad]
2026-08-14 docs: add 3D print settings and calibrated fit values to mechanical.md
    Document per-part slicer settings, calibrated bearing/shaft diameters, and renumber material section.
2026-08-14 docs: add classic electrical schematics for wiring
    Generate SVG circuit diagrams (power, signals, overview) and document them in wiring.md.
2026-08-14 hardware: add KiCad wiring schematic project
    Generate lidar.kicad_pro with module symbols and document it in wiring.md.
    [lidar.kicad_sch]
2026-08-14 fix(hardware): correct KiCad property hide flag syntax
    Place hide inside effects blocks so lidar.kicad_sch loads in KiCad.
    [lidar.kicad_sch]
2026-08-15 docs: add step-by-step assembly illustrations
    Generate PNG/SVG images for each assembly stage and embed them in assembly.md.
    [assembly_steps.scad]
2026-08-15 Adapt berceau LiDAR pour STL-19P et clarifier le montage moteur.
    Le berceau cible les 3 oreilles M2,5 du STL-19P (46,8 × 38,59 mm) avec
    passage nappe en bas ; la doc décrit aussi les moteurs NEMA à trous traversants.
    [assembly.scad, base_plate.stl, lidar_cradle.scad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]
2026-08-15 docs: aligner toute la documentation sur le STL-19P et le matériel réel.
    Reflecte la variante reçue (3 oreilles, 5000 Hz), l'incompatibilité BLDC,
    les cotes de collision recalculées et l'insert trépied 10×8 mm.
2026-08-15 feat(firmware): ajouter le driver MPU6050 et le nivellement au scan.
    Mesure la gravité sur 10 s avant chaque balayage, expose la télémétrie IMU
    sur le panneau web et signale les chocs (> 0,3°) via le protocole UDP.
2026-08-15 feat(web): état matériel et bouton redémarrage sur le panneau.
    Affiche Wi-Fi, LiDAR, TMC2209, MPU6050 et moteur avec pastilles OK/Ko,
    expose les champs hw_* dans /api/status et ajoute POST /api/reboot.
    [config.h, ota.cpp, scanner.cpp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]
2026-08-15 fix(web): ne pas afficher l'entraînement OK sans TMC ni homing.
    Le statut moteur ne repose plus sur la broche EN seule ; OK uniquement
    après homing StallGuard réussi, Ko si le TMC2209 est absent.
    [config.h, ota.cpp, scanner.cpp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]
2026-08-15 fix(web): fusionner TMC2209 et entraînement en une seule ligne.
    Évite le doublon Ko/TMC dans la section Matériel ; la ligne Entraînement
    affiche driver, StallGuard et état du homing.
    [config.h, ota.cpp]
2026-08-15 docs: aligner la doc sur le firmware 0.4.3 et retirer KiCad.
    Met à jour panneau web, MPU6050, débits STL-19P et procédures de calibration ; supprime le projet hardware/KiCad devenu redondant avec les schémas SVG.
    [lidar.kicad_sch]
2026-08-15 feat(web): section MPU6050 dédiée sur le panneau embarqué.
    Affiche g live, |g|, tangage/roulis, référence de nivellement et choc ; expose imu_has_ref et imu_ref_* dans /api/status (v0.4.4).
2026-08-16 fix(mech): corriger le perçage berceau STL-19P selon datasheet § 5.1.
    Oreilles lat. à 31,92 mm, connecteur à 38,59 mm, passage câble Ø14 ; regénère lidar_cradle.stl.
    [assembly_steps.scad, lidar_cradle.scad, lidar_cradle.stl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]
2026-08-16 fix(mech): perçages M2,5 traversants et fenêtre câble séparée.
    Évite le chevauchement du trou Ø14 avec les oreilles ; perce toute l'épaisseur de la platine et écarte les nervures.
    [assembly_steps.scad, lidar_cradle.scad, lidar_cradle.stl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]
2026-08-16 fix(mech): recaler le berceau sur le bord câble du datasheet STL-19P.
    Les 2 oreilles sont à 6,67 mm du connecteur, pas à 31,92 mm ; encoche câble ouverte en bas du rebord.
    [assembly_steps.scad, lidar_cradle.scad, lidar_cradle.stl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]
2026-08-16 feat(mech): coupon d'empreinte STL-19P et fente nappe traversante.
    Permet de valider trous et câble sans réimprimer le berceau ; la nappe passe par une fente ouverte en bas de la platine.
    [assembly_steps.scad, lidar_cradle.scad, lidar_cradle.stl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]
2026-08-16 fix(mech): ressouder le berceau LiDAR en une seule pièce.
    La fente nappe coupait le voile central ; deux voiles latéraux relient
    moyeu et platine sans bloquer le passage du câble.
    [lidar_cradle.scad, lidar_cradle.stl, test_lidar_fit.scad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]
2026-08-16 fix(mech): fusionner le voile dans le moyeu du berceau.
    Épaulement traversant la paroi sous le rétreint, puis deux bras
    vers la platine, pour éviter un joint collé au cylindre.
    [lidar_cradle.scad, lidar_cradle.stl]
2026-08-16 fix(mech): entraxe vertical STL-19P à 31,92 mm.
    Les deux trous côté câble étaient 4,1 mm trop loin de l'oreille haute
    (31,92 lu comme cote de corps au lieu de l'entraxe des perçages).
    [lidar_cradle.stl, params.scad, test_lidar_fit.stl]
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2026-08-22 feat(fw): homing StallGuard par UART, sans broche DIAG.
    Le TWOTREES n'expose pas DIAG sur le header ; SG_RESULT sur PDN
    suffit. Firmware 0.4.5.
    [config.h, generate_schematic_svgs.py, generate_wiring_svgs.py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]
